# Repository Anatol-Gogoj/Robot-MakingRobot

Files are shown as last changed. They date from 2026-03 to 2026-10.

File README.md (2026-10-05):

# Robot-Making Robot (RMR)

Associated with https://arxiv.org/abs/2608.00369

A custom 3-axis gantry robot driven by Marlin firmware on an Arduino Mega 2560. This is **not** a 3D printer — it's a pick-and-place / dispensing system with three auxiliary linear actuators, two servos, and a solenoid valve. Marlin is repurposed here purely as a motion controller because it provides production-grade G-code parsing, trapezoidal motion planning, and multi-axis stepper coordination out of the box.

## Repository Structure

```
Robot-MakingRobot/
├── Marlin-2.1.2.7/              # Full Marlin 2.1.2.7 source tree
│   └── Marlin/
│       ├── Configuration.h          # Main firmware config (heavily customized)
│       ├── Configuration_adv.h      # Advanced config + SPINCOATER feature flag
│       └── src/
│           ├── pins/ramps/
│           │   └── pins_RAMPS_14_RMR.h  # Custom pin mapping (J endstop on pin 23, Serial2 freed)
│           ├── core/boards.h            # Board ID registration (patched)
│           ├── pins/pins.h              # Board routing (patched)
│           ├── feature/
│           │   ├── spincoater.h         # ODrive S1 communication namespace
│           │   └── spincoater.cpp       # ODrive Serial2 raw ASCII protocol layer
│           ├── gcode/calibrate/G28.cpp  # Custom homing order (patched)
│           ├── gcode/control/
│           │   ├── M42.cpp              # DIRECT_PIN_CONTROL (patched: S<=1 guard)
│           │   ├── M280.cpp             # Servo handling (patched)
│           │   ├── M750.cpp             # Spincoater spin cycle
│           │   ├── M751_M752.cpp        # Spincoater home datum / index search
│           │   ├── M753.cpp             # ODrive UART diagnostic
│           │   └── M754.cpp             # ODrive encoder configuration dump (read-only)
│           ├── MarlinCore.cpp           # Patched: spincoater disarm in kill() and in setup()
│           └── inc/SanityCheck.h        # Servo deactivation check bypass (patched)
├── SpincoaterStage/              # Benchtop test firmware (Nano RP2040 — reference only)
│   ├── src/main.cpp                 # Standalone spincoater firmware v2.6
│   ├── SpincoaterDashboard.html     # Standalone spincoater Web Serial dashboard
│   └── INTEGRATION_PLAN.md         # Integration design rationale (STALE — see note below)
├── RMR_Controller.html           # Unified Web Serial controller (click-optimised, debug/tuning)
├── RMR_Touch.html                # Touchscreen-optimised Web Serial UI (operation)
├── RMR_SegmentRunner.html        # Standalone segment runner + named recipes (E-axis dispense — port before use)
├── fullcode.gcode                # Production DEA layer program (dispense step still E-axis — port before use)
├── LayerCycle.gcode              # Spin-coating layer cycle (E-axis dispense — port before use)
├── LayerCycle.segments.gcode     # LayerCycle with segment markers + parameters for the Segment Runner
├── SpinCoatUVCure.gcode          # April 2026 Copilot protocol, never run (E-axis)
├── DemoProgram.gcode             # Demo pick-and-place cycle
├── tests/                        # Stub-DOM harness for the browser pages (Node; never run here)
├── tools/contrast_check.py       # WCAG contrast checker for the UI colour themes
├── pi-panel/                     # Raspberry Pi touch-panel bridge, GPIO config, systemd unit, README
├── PIN_MAP.md                    # Consolidated pin map + wiring reference (authoritative bench doc)
├── SpincoaterPinMap.jfif         # ODrive S1 J11 connector pinout image
├── ODRIVE_CONFIG.md              # ODrive S1 configuration as recorded 2026-08-13
├── RUN_SHEET.md                  # Bench run sheet (four lanes, Tasks 1–15) with dated results
├── HANDOFF-2026-09-14.md         # Frozen: the 2026-09-14 consolidation handoff
├── HANDOFF-2026-08-19.md         # Superseded: August bench results
├── HANDOFF-2026-08-14.md         # Superseded: the modulo-one-turn index finding
├── HANDOFF.md                    # Original 2026-08-11 handoff: reasoning behind the spincoater stack
├── AI_ATTRIBUTION.md             # AI assistance disclosure
├── CAD/                          # FreeCAD sources + STEP exports for printed parts
├── claude.md                     # Detailed firmware architecture & project docs
└── README.md                     # This file
```

`RMR_Controller.html` and `RMR_Touch.html` **are** the machine's UI — the Controller for
debugging and tuning, the Touch UI for operation. Do not start a third one.

`SpincoaterStage/INTEGRATION_PLAN.md` is a historical design record, not a plan. Its M750
parameter table is wrong: it documents `A`/`C` as accelerations in rev/s², but the firmware
parses them as ramp *times* in seconds. Treat `claude.md` as authoritative.

## Current State

The spincoater firmware stack that was open all summer (#38, #39, #51, #56, #57, #58, plus #70 M754
and #76) was merged into `main` on 2026-09-14 as one consolidation, PR #106; the September UI work
(sequencer homing gate, argon purge, colour themes, Touch UI syringe C-axis port) followed as PR #107.
The merged firmware compiles (`pio run -e mega2560`); the last hardware evidence recorded in this repo is
from the 2026-08-17/19 bench sessions. The Spin Coater Subsystem section below describes `main`.

`HANDOFF-2026-09-14.md` records the consolidation: what merged, the conflict resolutions that were
decisions, and the four UI pull requests that were deliberately left out. It and the older `HANDOFF*.md`
files are frozen history; session state is not kept in the repo. `RUN_SHEET.md` is the bench checklist;
`HANDOFF-2026-08-19.md` holds the August results.

## Hardware Overview

### Motion System

The gantry has three Cartesian axes (X, Y, Z) plus three auxiliary linear actuators. The Filter Feed and Syringe Height are mapped as Marlin I/J linear axes (with full homing and endstop support), while the Syringe is the sole extruder (E0). All stepper drivers are external DM556T units (optoisolated PUL/DIR/ENA inputs) driven directly from Mega GPIO pins — there is no RAMPS shield, though the pin mapping inherits from RAMPS 1.4 for the gantry axes.

| Marlin Axis | G-Code | Function | Drive | Steps/mm |
|---|---|---|---|---|
| X | X | Gantry X | GT2-14 belt | 57.14 |
| Y + Y2 | Y | Gantry Y | GT2-14 belt (2 motors, 2 drivers, firmware-synchronized via `Y2_DRIVER_TYPE`) | 57.14 |
| Z | Z | Gantry Z | 5 mm lead screw | 320 |
| I | A | Filter Feed | 5 mm lead screw | 320 |
| E0 | E | Syringe | 1 mm lead screw | 1600 |
| J | B | Syringe Height | 5 mm lead screw | 320 |

Steps/mm formula: `(motor_steps_per_rev × microstepping) ÷ linear_travel_per_rev`. All drivers are set to 1/8 microstepping (1600 steps/rev with 200-step motors).

### Tuned Motion Parameters

| Parameter | X | Y | Z | A (Filter) | B (Syr.Ht) | E (Syringe) |
|---|---|---|---|---|---|---|
| Max feedrate (mm/s) | 400 | 333 | 50 | 33 | 50 | 8 |
| Max feedrate (mm/min) | 24000 | 20000 | 3000 | 2000 | 3000 | 500 |
| Max acceleration (mm/s²) | 500 | 200 | 100 | 150 | 50 | 500 |
| Travel limit (mm) | 770 | 200 | 186 | 343 | 295 | 125 |

> Y travel reaches 200 mm only on the right half (X ≥ 350); on the left half keep Y ≤ 150 mm to clear fixtures.

### End Effectors and Peripherals

- **Gripper servo** — GPIO 5, `M280 P0 S<angle>`, range 90° (closed) to 170° (open)
- **Lid servo** — GPIO 6, `M280 P1 S<angle>`, 0–180° range
- **UV lamp relay** — GPIO 4, `M42 P4 S1` = ON / `M42 P4 S0` = OFF (current active-HIGH modules)
- **Solenoid valve relay** — GPIO 42, `M42 P42 S1` = ON / `M42 P42 S0` = OFF (current active-HIGH modules)

Both relays are opto-isolated modules powered from a dedicated 3.3 V buck converter rail (shared ground with the Mega). The current modules are active-HIGH (S1 = energize). The original Bestep JQC3F-03VDC-C modules were active-LOW (S0 = energize). The HTML UI uses explicit ON/OFF button pairs with hardcoded S values, so correct polarity is handled by which button the user presses.

Servos deactivate 2 seconds after positioning (`DEACTIVATE_SERVOS_AFTER_MOVE`) to prevent PWM jitter.

### Limit Switches

All five homing axes have endstops:
- X endstop on pin 3 (X_MIN, interrupt-capable)
- Y endstop on pin 14 (Y_MIN)
- Z endstop on pin 40 (Z_MIN — moved from pin 18/TX1 due to EMI)
- I (Filter Feed) endstop on pin 15 (I_MAX — homes to far end)
- J (Syringe Height) endstop on pin 23 (J_MIN — moved from pin 17/TX2 to free Serial2 for ODrive)
- Syringe (E0) has no endstop

All switches are normally-open, wired common→GND / NO→signal, with internal pullups enabled. `G28` (home all) is safe to send.

## Firmware Details

### Custom Board Definition

A custom board `BOARD_RAMPS_14_RMR` (ID **1025**) inherits from stock RAMPS 1.4 and overrides pin assignments for the I/J linear axes and E0 extruder. **ID 1020 is stock `BOARD_RAMPS_14_EFB` — using it silently selects the wrong pin file.** The following Marlin source files are modified:

| File | Change |
|---|---|
| `Marlin/src/pins/ramps/pins_RAMPS_14_RMR.h` | Custom pin map, conflict resolution, J endstop on pin 23 |
| `Marlin/src/core/boards.h` | Board ID `1025` registration (`boards.h:50`) |
| `Marlin/src/pins/pins.h` | Routing `MB(RAMPS_14_RMR)` → pins file |
| `Marlin/src/gcode/calibrate/G28.cpp` | Custom homing order Z→Y→J→X→I, gripper close before X |
| `Marlin/src/gcode/control/M42.cpp` | Added `pin_status <= 1` early return so digital-only writes skip `hal.set_pwm_duty()` on AVR (prevents Timer0/Timer1 conflicts) |
| `Marlin/src/gcode/control/M280.cpp` | Servo clamp removed (soft limits in HTML only). POLARGRAPH gate on T parameter removed — `M280 Px S<angle> T<ms>` now works on all servos for timed linear interpolation. |
| `Marlin/src/gcode/control/M750.cpp` | Spincoater spin cycle handler |
| `Marlin/src/gcode/control/M751_M752.cpp` | Spincoater home datum / index search |
| `Marlin/src/gcode/control/M753.cpp` | ODrive UART diagnostic |
| `Marlin/src/feature/spincoater.h/.cpp` | ODrive S1 Serial2 raw ASCII communication layer |
| `Marlin/src/MarlinCore.cpp` | Spincoater disarm in `kill()` and in `setup()` (startup safety disarm) |
| `Marlin/src/inc/SanityCheck.h` | DEACTIVATE_SERVOS_AFTER_MOVE check bypassed |
| `Marlin/Configuration_adv.h` | SPINCOATER feature flag + defaults; `DIRECT_PIN_CONTROL` for M42 relays; `EMERGENCY_PARSER` enabled so M112 bypasses the queue during a blocking M750 |
| `ini/features.ini` | Build system registration for spincoater source files |

Several stock RAMPS pins are reassigned to free GPIOs for the auxiliary motors (e.g., pin 2 repurposed from X_MAX to I_STEP, pin 9 from FAN to I_DIR). Pins 16/17 are occupied by Serial2 (ODrive link). Pins 19/20/21 conflict with Serial1 and I2C — those peripherals cannot be used without rewiring.

### Key Configuration Choices

- `EXTRUDERS 0` — no extruder; the syringe is the homeable K axis (G-code `C`), Filter Feed and Syringe Height are the I/J linear axes (`A`/`B`), all with endstops and homing
- `AXIS4_NAME 'A'`, `AXIS5_NAME 'B'`, `AXIS6_NAME 'C'` — G-code letters for the I/J/K axes
- All temperature sensors disabled (`TEMP_SENSOR_* 0`) — no heaters on this machine
- `EXTRUDE_MINTEMP 0` — moot since `EXTRUDERS 0`: there is no E axis and no cold-extrusion check
- `INVERT_Z_DIR`, `INVERT_I_DIR`, `INVERT_J_DIR`, `INVERT_K_DIR` all `true` — Z/I/J verified by physical testing; K (syringe) is flipped so `-C` homes toward the open end — verify on first use
- Custom homing order: lid open (30°) → Z → Y → J(Syr.Ht) → gripper close (90°) → X → I(Filter Feed)
- `DEACTIVATE_SERVOS_AFTER_MOVE` with 2-second hold — prevents servo jitter

## Spin Coater Subsystem

The spin coater uses an ODrive S1 motor controller driving a D5312s-330kV brushless motor with an AMT102 incremental encoder. The ODrive is controlled directly from the Mega 2560 over Serial2 (pins 16/17) at 115200 baud using the ODrive raw ASCII protocol — there is no second Arduino.

```
Mega 2560 (Marlin + M750/M751/M752/M753/M754)  ──Serial2 (115200)──►  ODrive S1  ──►  Motor
```

### Spincoater G-Codes

```gcode
M750 S5000 D30 A5 C1 H1   ; spin cycle: 5000 RPM, 30s dwell, 5s ramp-up, 1s ramp-down, home after
M751                       ; set current position as the 0° home datum
M752                       ; encoder index search, then move back to the saved datum
M753                       ; UART diagnostic — probes ODrive link, reports raw response
M754                       ; encoder configuration dump (read-only) — answers the index-reference question over UART
```

**M750** — blocking spin cycle. `S` = RPM, `D` = dwell seconds, `A` = ramp-up **time in
seconds**, `C` = ramp-down **time in seconds**, `H` = home after (0/1). Defaults are
S5000 D30 A5 C1 H1. All four numeric values must be > 0 or the command aborts with
`ERR: All values must be > 0`. `A`/`C` are converted internally to ODrive ramp rates
(`accel = (rpm/60)/A` rev/s²) — they are *not* accelerations.

Phase order is: boot (first call only) → CONNECTING → Vbus read → CALIBRATING/CLOSED_LOOP →
RAMP_UP → MEASURING → RAMP_DOWN → SETTLING → STOPPED → optional index home. It emits
real-time telemetry and Welford's online statistics (mean, std dev, min, max RPM) over serial.
The cycle can abort at several points; every abort still returns a bare `ok` to the host
(see gotcha 13). Judge success only by the terminal line:
`OK: CYCLE_COMPLETE` vs `ERR: CYCLE_COMPLETE_NO_HOME`.

**M751** — sets the current encoder position as the 0° datum. It can now fail: it refuses
without two consistent position reads, and refuses if the axis is turning faster than about
3 RPM. Success prints `OK: HOME_SET`; a failure *after the ODrive boots* prints a reason plus
`ERR: HOME_SET_FAILED`. If the deferred `boot()` itself fails, M751 prints only
`ERR: ODrive boot failed` and emits **no terminal marker at all**.

**M752** — runs the ODrive encoder index search, verifies `axis0.procedure_result`, then
re-arms closed loop and commands a slow trapezoidal move **back to the saved datum**
(vel_limit 0.25 turns/s ≈ 15 RPM, 8 s watchdog). **The chuck physically rotates.** It never
moves an existing datum; it only establishes one if none exists. Success prints
`OK: INDEX_COMPLETE`; any failure *after the ODrive boots* prints `ERR: INDEX_HOME_FAILED` (and,
if it was the settle that timed out, `ERR: INDEX_INCOMPLETE -- datum not reached` immediately
before it). If the deferred `boot()` itself fails — a dead link, the most likely bench failure and
the leading suspect in issue #46 — M752 prints only `ERR: ODrive boot failed` and emits **no
terminal marker at all**.

A common M752 refusal is `ERR: Position <n> is >1 turn from home datum <n> -- refusing settle`.
It means the reported position and the datum are in different encoder frames, so the move
would crawl for thousands of turns. The only way out is `M751`. Whether an ODrive 0.6.x index
search actually re-references `pos_estimate` is **unverified on this machine** and is the
open bench question behind this behaviour.

**M753** — UART diagnostic only. It calls `Spincoater::init()`, sends `r vbus_voltage`, and
dumps raw bytes as `DIAG:` lines for up to 2 s. It does not boot the ODrive, does not touch
the datum, and does not move anything — so it is the correct first command on a cold bench.

The ODrive *probe/boot* sequence is deferred to the first M750/M751/M752. Serial2 itself is
opened during Marlin `setup()`, which transmits two ODrive IDLE requests on **every** board
reset (startup safety disarm), so pin 16 is not idle at power-on.

The `SpincoaterStage/` directory contains the original standalone firmware (Nano RP2040 Connect) and dashboard used for benchtop testing. These are reference files only — the production system uses the integrated Marlin M-codes, and none of the Nano's `SPIN`/`STOP`/`HOME` text commands exist in Marlin.

## Building and Uploading

### Prerequisites

- [VS Code](https://code.visualstudio.com/) with the [PlatformIO](https://platformio.org/) extension
- USB cable to the Arduino Mega 2560

### Build Steps

1. Open the `Marlin-2.1.2.7/` directory in VS Code with PlatformIO.
2. Ensure `platformio.ini` has `default_envs = mega2560`.
3. Build: click the PlatformIO checkmark button, or run:
   ```
   pio run -e mega2560
   ```
4. Upload: click the PlatformIO arrow button, or run:
   ```
   pio run -e mega2560 -t upload
   ```

### Serial Connection

Connect via the included `RMR_Controller.html` or `RMR_Touch.html` web UI (Chrome/Edge, Web Serial API), Pronterface, or any serial terminal at **250000 baud**. Port is typically `/dev/ttyACM0` on Linux or `COM3` on Windows.

## Using the Machine

### Startup Sequence

```gcode
G28              ; home all axes (lid open → Z → Y → J → gripper close → X → I → K/Syringe) — safe, all have endstops
G28 X Y Z A B    ; home the gantry + aux axes WITHOUT retracting the syringe
```

A bare `G28` also homes the syringe (Marlin K axis, G-code letter `C`) and leaves the plunger fully open at `C0`, so no `G92` reset is needed — the syringe is a homed absolute axis.

### Moving the Gantry

```gcode
G1 X100 Y50 F3000    ; move to (100, 50) at 50 mm/s
G1 Z10 F600          ; lower Z 10 mm at 10 mm/s
```

Feedrates are in mm/min. Max recommended: X 24000, Y 20000, Z 3000.

### Driving Auxiliary Motors

Each auxiliary motor has its own G-code axis letter — no tool switching needed:

```gcode
G1 A50 F1000     ; move Filter Feed to 50 mm at 1000 mm/min
G1 B20 F600      ; move Syringe Height to 20 mm
G1 C5 F300       ; push the syringe plunger to 5 mm from home (+C = dispense; C0 = fully open)

G91              ; relative mode
G1 C5 F300       ; dispense a further 5 mm from the current plunger position
G90              ; back to absolute mode
```

The syringe is a homed absolute axis (Marlin K axis, G-code letter `C`; `C0` = plunger fully open, soft-endstop limit 125 mm). Do **not** use `G92 C0` to re-zero it — that defeats the soft endstops. For a relative "dispense N mm" nudge, wrap the move in `G91` / `G90` as shown. The old extruder idioms `G1 E…` / `G92 E0` are silently ignored by the current firmware (there is no E axis).

### Servos, UV Lamp, and Solenoid

```gcode
M280 P0 S90      ; close gripper (90°)
M280 P0 S170     ; open gripper (170°)
M280 P1 S0       ; set lid servo to 0°
M280 P1 S30 T800 ; open lid over 800ms (timed linear interpolation)

; Relays (current modules are ACTIVE-HIGH):
M42 P4  S1       ; UV lamp ON        (active-high)
M42 P4  S0       ; UV lamp OFF
M42 P42 S1       ; solenoid valve OPEN  (active-high)
M42 P42 S0       ; solenoid valve CLOSED
```

The current relay modules are active-HIGH (S1 = energize, S0 = de-energize). The original Bestep JQC3F-03VDC-C modules were active-LOW (S0 = ON, S1 = OFF). Always comment the intent in production G-code (e.g. `M42 P4 S1 ; UV_ON`) because the S-value meaning depends on which relay module is installed.

### Spin Coating

```gcode
M753                       ; UART diagnostic — safe first command, does not boot or move
M752                       ; index search + return to datum — THE CHUCK ROTATES
M751                       ; set current position as 0° datum (refuses if the rotor is moving)
M750 S3000 D10 A5 C1 H1    ; 3000 RPM, 10s dwell, 5s ramp-up, 1s ramp-down, home after
```

`A` and `C` are ramp **times in seconds**, not accelerations. `A5 C1` means a 5-second
ramp-up and a 1-second ramp-down.

M750 is blocking — Marlin will not process further commands until the cycle completes,
except `M112`/`M108`/`M410`, which `EMERGENCY_PARSER` dispatches straight from the serial
RX path. Use within G-code programs to sequence spin coating after gantry positioning
(see `fullcode.gcode`).

Watch the serial log, not the phase indicator. Success and failure are distinguished only by
the terminal line:

| Command | Success | Failure |
|---|---|---|
| M750 | `OK: CYCLE_COMPLETE` | `ERR: CYCLE_COMPLETE_NO_HOME` (H1 home failed), or no terminal line at all on an earlier abort |
| M751 | `OK: HOME_SET` | `ERR: HOME_SET_FAILED` |
| M752 | `OK: INDEX_COMPLETE` | `ERR: INDEX_HOME_FAILED` |

`WARN:` lines carry every datum-integrity message (datum preserved, datum established,
"run M751"). Neither UI highlights them — read them in the console.

### Runtime Tuning (no rebuild needed)

```gcode
M201 X500 Y200 Z100 A150 B50 C500   ; set max acceleration (mm/s²) — C = Syringe
M203 X400 Y333 Z50 A33 B50 C8       ; set max feedrate (mm/s) — C = Syringe
M500             ; NOT AVAILABLE — EEPROM_SETTINGS is disabled (Configuration.h:2217).
                 ;   Reports "EEPROM disabled" and saves nothing.
M501             ; DESTRUCTIVE — does NOT load from EEPROM. It resets every setting to the
                 ;   compiled-in Configuration.h defaults, discarding all runtime tuning.
M503             ; report all active settings (works)
```

### Diagnostics

```gcode
M119             ; report endstop states
M114             ; report current position
M999             ; recover from "stopped" errors (NOT from M112 — after M112, reset/reconnect the board)
```

## Web Controller

There are two UIs, both standalone browser pages driving the machine over Web Serial
(Chrome/Edge required): `RMR_Controller.html` (click-optimised, full control — use for
debugging and tuning) and `RMR_Touch.html` (touchscreen-optimised, tabbed layout — use for
operation). They share the same serial contract and the same spincoater panel logic.

`RMR_Controller.html` features:

- XY/Z jog pads with configurable step sizes and per-axis feed sliders
- Per-axis auxiliary motor controls with individual feed sliders (A, B, C)
- Collapsible acceleration tuning panel (M201) with per-axis sliders and EEPROM save
- Gripper servo slider (90°–170°) with Open/Close buttons and full-range override textbox
- Spincoater panel — RPM/Duration/Rise/Sink inputs, live RPM gauge, SVG circular position dial, Welford stats cards, phase indicator, and four buttons:
  - **Start Spin** (M750), **Set Home** (M751), **Index Home** (M752 — rotates the chuck)
  - **Stop** — sends **M112**. This is not a soft stop: it kills the firmware, freewheels the chuck, needs a board reset to recover, and loses the datum. The Process Sequencer's Stop is the soft one: it sends `M410`, which a running `M750` polls and honours by zeroing the rotor (`STATE:STOPPED` + `OK: ABORTED`, untested on hardware).
- E-Stop (M112) — recover via board reset (disconnect/reconnect USB); the M999 Reset button only clears the softer "stopped" state
- Position readout with auto-report polling
- G-code program runner with Load .gcode, Run/Pause/Stop, and wait-for-ok sequencing
- Raw G-code input with command history
- Keyboard shortcuts: Arrow keys = XY, PgUp/PgDn = Z, Esc = E-Stop
- **Process Sequencer** tab — Homing / Syringe / Spin Coater / UV / Stamp recipe blocks with per-block Run, Run All and Repeat. The Syringe block doses with a post-dose dwell (2 s default) before a pullback at its own feed (sized on the bench to stop the drip; the max-retract cap defaults to 2 mm), dose / retract / barrel-stroke guards, a purge routine and an idle warning — the numbers for the 150 mL catheter-tip syringe are in `DISPENSE_150ML.md`
- **Run Log** tab — a per-device manufacturing log for multilayer DEAs that mirrors the MLDEA reference sheet: one row per dielectric layer (dispense time, volume, RPM set / settled, UV on, cure set / actual, nominal height) and one per electrode (P/N, filter pressed, hold, feeder side), filled in automatically by the sequencer, editable cell by cell (the recorded value is kept underneath), with **Hold** / **Break** buttons that pause a run between commands at the end of the layer (or after the next cure / current block) and record the pause as a row, a **Log on/off** switch, manual "mark now" buttons (all filter pressing is by hand today), a journal of every event including re-runs, and Excel / CSV / JSON export — the `.xlsx` reproduces the reference sheet's layout and formulas. Saved in the browser; optionally auto-saved to a folder you pick. Design notes: `RUN_LOG_PLAN.md`
  - **Homing gate:** Syringe, UV and Stamp stay locked until a full home (bare `G28`) has completed; Spin Coater and Homing are always available. Re-locks after E-stop, reset, motors-off, a firmware restart or a motor-power loss.
  - **Argon purge:** the UV block can open the argon solenoid a configurable number of seconds before UV-on and close it a configurable number of seconds after UV-off (negative values allowed); the lamp and solenoid always end off/closed, even on Stop.
  - UV progress is drawn on a canvas showing the argon / UV / argon segments — click it to cycle bar → wave → snake.
- **Colour themes** (header selector; Touch UI: Advanced tab): Auto, Midnight, Tol dark, Tol light, Tol high-contrast — Paul Tol colour-blind-safe palettes, every text/surface pair WCAG AA checked by `tools/contrast_check.py`; keyboard focus rings and reduced-motion support.

`RMR_Touch.html` is the touch-panel variant of the same UI (large controls, tabbed layout) with the same sequencer, themes and Pi-bridge transport.

## Important Gotchas

1. **Axis naming:** G-code uses `A` and `B` for the Filter Feed and Syringe Height axes (not `I`/`J`). This applies to all commands: `G1`, `M201`, `M203`, `G28`, etc.
2. **The syringe is the C axis, not an extruder:** `EXTRUDERS 0`; the plunger is Marlin's K axis with G-code letter `C` (`+C` = dispense, `C0` = fully open, homed, soft-endstop 0–125 mm). `G92 E0` / `G1 E…` are silently ignored — no error — so any program still using them dispenses nothing. `fullcode.gcode`, `LayerCycle*.gcode`, `SpinCoatUVCure.gcode` and `RMR_SegmentRunner.html` still do (see `HANDOFF-2026-09-14.md` §5).
3. **Filter Feed homes to MAX:** Unlike all other axes which home to MIN, the Filter Feed (A axis) homes to its far-end endstop (I_MAX, pin 15).
4. **Servo deactivation:** Servos go limp 2 seconds after positioning. If the gripper needs to actively hold force, `DEACTIVATE_SERVOS_AFTER_MOVE` must be disabled (requires rebuild) or an external servo controller used.
5. **E-Stop recovery:** `M112` fully kills the firmware and **cannot** be recovered with `M999` — reset the board (disconnect/reconnect USB or power-cycle). On reboot the firmware automatically disarms the spincoater. `M999` only recovers from the softer "stopped" state. `EMERGENCY_PARSER` is enabled, so `M112`/`M108`/`M410` act immediately from the serial RX path instead of queueing behind a blocking M750. Side effect: `M0`/`M1` are now compiled in and will **pause until an `M108` arrives** — previously they returned "Unknown command". Any production G-code containing `M0`/`M1` will stall. **This side effect has not been bench-checked.**
6. **Pins 16/17 (Serial2)** are occupied by the ODrive S1 link. **Pins 19/20/21** conflict with Serial1 and I2C. Adding an I2C LCD or additional serial device requires rewiring motors.
7. **Direction inversions:** Z, I, and J axes all have `INVERT_*_DIR true`. If a new axis is added or a motor is rewired, verify direction during first test.
8. **AVR `println()` and ODrive:** On AVR, `Serial.println()` sends `\r\n`. The ODrive ASCII protocol expects bare `\n` — the stray `\r` causes "unknown command" errors. All ODrive UART writes use `print()` + `write('\n')` instead.
9. **M42 hijacks hardware timers on AVR:** Stock Marlin's `M42.cpp` always falls through to `hal.set_pwm_duty(pin, pin_status)` on AVR, which maps to `analogWrite()` and grabs the pin's hardware timer compare unit — even for `S0` and `S1`. On pins tied to Timer1 (e.g. pin 11 = OC1A, used by Marlin's stepper ISR) this causes intermittent pin-fighting where `M42` appears to work once and then stops. Our patched `M42.cpp` adds a `pin_status <= 1` early return so digital-only writes always take the pure `digitalWrite` path. For relay pins, prefer pure-GPIO pads with no timer compare unit (pin 42 = PL7 is used for the solenoid valve; pin 4 = OC0B is tolerable only because of the patch).
10. **Relay module polarity:** The current relay modules are active-HIGH (`M42 Pxx S1` = energize, `M42 Pxx S0` = de-energize). The original Bestep JQC3F-03VDC-C modules were active-LOW (reversed polarity). The HTML UI uses explicit ON/OFF button pairs with hardcoded S values, so the correct polarity is handled by button choice regardless of module type.
11. **`Servo::move()` vs `Servo::write()` in interpolation loops:** `move()` calls `attach + safe_delay(SERVO_DELAY) + detach` per invocation — with SERVO_DELAY=2000, that is 2s per step. For tight ramp loops, use `write()` with manual `attach(0)` before and `write(final)+safe_delay(250)+detach` after. The M280 T parameter uses this approach. Default lid ramp time in the HTML UIs is 800ms.
12. **M752 and `M750 ... H1` physically rotate the chuck.** After the index search the firmware re-arms closed loop and commands a slow trapezoidal move back to the saved datum — up to ~15 RPM for up to 8 seconds. Do not run either with the lid open or with anything resting on the chuck.
13. **`ok` does not mean a spincoater command succeeded.** Every M750/M751/M752 failure path returns normally, so Marlin still emits `ok`. The Program Runner's wait-for-ok will happily continue to the next layer after a failed home. Judge success only by the terminal marker (`OK: CYCLE_COMPLETE` / `OK: INDEX_COMPLETE` / `OK: HOME_SET`).
14. **Spincoater failure tokens used to render as successes.** Until 2026-09-14 both UIs matched tokens by substring, so `ERR: CYCLE_COMPLETE_NO_HOME` showed a green "Cycle complete" and `ERR: HOME_SET_FAILED` showed "Home datum set". `main` now dispatches `ERR:` / `OK:` by message class (PR #84's commit, merged with #106): any `ERR:` sets the error phase, and the Touch UI toasts it. Still unhandled: `WARN:` lines, and the `STATE:STOPPED` / `OK: ABORTED` pair a Process Sequencer Stop produces — read the console.
15. **The spincoater datum is RAM-only.** `_homePos` is not stored in EEPROM, so it is lost on every board reset — including the DTR reset the browser triggers when it connects, and the reset that is the only recovery from `M112`. After any reconnect or E-stop, re-run `M751` before any layer that depends on angular registration.
16. **`M112` disarms the spincoater, it does not brake it.** `kill()` requests ODrive IDLE, so the rotor **freewheels** to a stop. This is deliberate — there is no confirmed brake resistor and regen from a high-RPM chuck could overvolt the DC bus. Coast-down time from full speed has never been measured on this machine.
17. **Sequencer homing gate:** the web UIs track "all axes homed" in the browser. A manual bare `G28` is followed by `M118 RMR:HOMED_ALL`, which Marlin prints back only after the homing finishes — that line unlocks the Syringe / UV / Stamp blocks on every client of the Pi bridge. Partial homing (`G28 X Z`) does not unlock; E-stop, `M999`, `M18`, a firmware restart or `MOTOR POWER LOST` re-lock.

## AI Attribution

Portions of this project's documentation, firmware configuration, and supporting code were generated or edited with the assistance of Claude (Anthropic). All AI-generated content was reviewed and validated by the project author. See [AI_ATTRIBUTION.md](AI_ATTRIBUTION.md) for details.

## License

The Marlin firmware is licensed under the GPL v3. See the `Marlin-2.1.2.7/` directory for full license text. Project-specific files (pin map, controller UI, configurations) are provided as-is for this specific machine build.

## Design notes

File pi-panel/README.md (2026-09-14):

# RMR Integrated Touch Panel (Raspberry Pi)

Turns a Raspberry Pi + a generic 10″ touchscreen into a built-in operator panel
for the machine. The Pi owns the USB link to the Arduino Mega (Marlin); the
existing web UI (`RMR_Controller.html`) runs in a browser on the Pi and talks to
the Pi over a **WebSocket** instead of the browser's Web Serial API.

Because the browser no longer needs Web Serial, **any browser works** — Firefox
or a lightweight WebKit kiosk (`cog`) — no Chromium requirement.

## Architecture

```
   10" touch  (HDMI video  +  USB touch-HID)
        │
   ┌────┴─────┐   browser (Firefox / cog kiosk) → RMR_Controller.html?transport=ws
   │  Pi 4/5  │        │  WebSocket ws://localhost:8765   (+ static HTTP :8000)
   │          │   ┌────┴─────────────┐
   │          │   │ rmr_bridge.py    │  owns the serial port, fans out to all clients
   │          │   └────┬─────────────┘
   └────┬─────┘        │
        │ USB  /dev/rmr-mega @ 250000     ← the only control link
   ┌────┴─────┐
   │ Mega 2560│   Marlin  (M750 drives the spincoater)
   └────┬─────┘
        │ Serial2 UART (pins 16/17, 115200)
   ┌────┴─────┐
   │ ODrive S1│──▶ motor
   └────┬─────┘
        ╎ USB → Pi  (OPTIONAL: /dev/rmr-odrive, for odrivetool / debugging only)
```

The ODrive is driven **by the Mega** over Serial2 (`M750/M751/M752`), so run-time
control is one USB link (Pi → Mega). Wiring the ODrive's USB to the Pi is only a
convenience for `odrivetool` during calibration/tuning — it is not used at run time.

## Hardware

- **Raspberry Pi 4 (2–4 GB) or Pi 5** — a Pi 3 struggles with a browser UI.
- **10″ touchscreen:** HDMI video + **USB-HID capacitive touch** is the most
  universal (plug-and-play on Linux, no driver). Avoid panels that need a vendor
  touch driver.
- Its own solid **5 V / 3 A** supply for the Pi (don't power it from the Mega).
- Active cooling if it lives in an enclosure.

## One-time setup

### 1. OS + repo
Install Raspberry Pi OS (64-bit, Bookworm). Clone this repo, e.g. to
`/home/pi/Robot-MakingRobot`.

### 2. Python bridge dependencies (isolated venv)
```bash
cd /home/pi/Robot-MakingRobot/pi-panel
python3 -m venv .venv
.venv/bin/pip install -r requirements.txt
```
`gpiozero` (for physical buttons) is already present in Raspberry Pi OS.

### 3. Stable serial device names (udev)
So the Mega is always `/dev/rmr-mega` regardless of USB enumeration order:
```bash
# find your board's USB IDs first:
lsusb
udevadm info -a -n /dev/ttyACM0 | grep -E 'idVendor|idProduct'
# edit 99-rmr-serial.rules to match, then:
sudo cp 99-rmr-serial.rules /etc/udev/rules.d/
sudo udevadm control --reload-rules && sudo udevadm trigger
```
Confirm `ls -l /dev/rmr-mega` now points at the Mega.

### 4. Test the bridge manually
```bash
cd /home/pi/Robot-MakingRobot
pi-panel/.venv/bin/python pi-panel/rmr_bridge.py \
    --port /dev/rmr-mega --baud 250000 \
    --serve-dir "$PWD" --http-port 8000 --ws-port 8765
```
You should see `[serial] opened /dev/rmr-mega` and `[ws] listening …`. Open a
browser on the Pi to **`http://localhost:8000/RMR_Controller.html`** — it
auto-detects HTTP and connects to the bridge; the console shows
`Bridge connected`.

### 5. Run on boot (systemd)
```bash
# edit paths/User in rmr-bridge.service if needed, then:
sudo cp pi-panel/rmr-bridge.service /etc/systemd/system/
sudo systemctl daemon-reload
sudo systemctl enable --now rmr-bridge.service
journalctl -u rmr-bridge -f      # watch it
```

### 6. Kiosk browser autostart (no Chromium needed)
Point a full-screen browser at the UI. Two good options:

- **Firefox kiosk:** `firefox --kiosk "http://localhost:8000/RMR_Controller.html"`
- **cog** (lean WPE WebKit): `sudo apt install cog && cog "http://localhost:8000/RMR_Controller.html"`

Autostart on Bookworm (labwc/wayfire desktop) — add to `~/.config/wayfire.ini`:
```ini
[autostart]
panel = firefox --kiosk http://localhost:8000/RMR_Controller.html
blank = swayidle timeout 0 'true'    # or disable screen blanking via raspi-config
```
On the older X11 desktop, put a `.desktop` launcher in `~/.config/autostart/`.
Disable screen blanking with `raspi-config` → Display, or `xset s off -dpms` (X11).

### 7. On-screen keyboard (touch input for text fields)
The panel has text/number fields (raw G-code, preset names, tunables), so add a
virtual keyboard:
- Wayland (Bookworm): `sudo apt install wvkbd` (or `squeekboard`)
- X11: `sudo apt install onboard` (or `matchbox-keyboard`)

## Using it

- **On the Pi:** `http://localhost:8000/RMR_Controller.html` (bridge mode auto-selected).
- **Touch layout:** swap the URL to `RMR_Touch.html` for the big-target UI (same
  bridge; it has the Process Sequencer as its **Recipe** tab).
- **From a phone/laptop on the LAN:** `http://<pi-hostname>.local:8000/RMR_Controller.html`
  — multiple clients can be connected at once; every serial line and every command
  (including physical-button presses) is mirrored to all of them.

### Transport selection (URL)
The page auto-picks its transport, override with query params:
| Situation | Transport | How |
|---|---|---|
| Served over `http(s)://` (the Pi) | WebSocket bridge | automatic |
| Opened as a local `file://` (dev laptop) | Web Serial | automatic |
| Force bridge | WebSocket | `?transport=ws` |
| Force Web Serial | Web Serial | `?transport=serial` |
| Bridge on another host/port | WebSocket | `?ws=ws://host:8765` |

The header also has a **Web Serial / Pi Bridge** dropdown that overrides the
auto-pick without a URL change; the choice is remembered (`localStorage`), so a
dev laptop served over `http://localhost` can switch to Web Serial once and stay
there. The dropdown is disabled while connected, and "Web Serial" shows as
`(n/a)` in insecure contexts (plain `http://` to a LAN IP), where the browser
does not expose the API — use `localhost`, `https://`, or a local `file://`.

## GPIO I/O: buttons, status tower, E-stop sense

All optional and off unless configured. Copy `rmr_io.example.json` to `rmr_io.json`,
edit, and it's passed with `--io …/rmr_io.json` (the systemd unit already does).
Pins are BCM GPIO numbers.

**Physical buttons (gloves / dirty hands)** — momentary buttons mapped to G-code.
Default wiring is button → GPIO pin and GND (internal pull-up, active-low). Each
press calls the same path as the UI and is echoed to every connected screen. A
`cmd` may hold several lines (`\n` inside the JSON string): the example `home_all`
button sends `G28` and then `M118 RMR:HOMED_ALL` — Marlin prints that marker back
only after the homing has finished, and every browser UI uses it to unlock the
Process Sequencer's homing gate (Syringe / UV / Stamp stay locked until a full home).

**Status tower + buzzer** — a red/amber/green tower light and buzzer driven from
machine state the bridge infers off the serial stream + connection:

| State | Tower | Meaning |
|---|---|---|
| `green` | steady | connected and idle/ready |
| `amber` | steady | active — a command was sent in the last ~1.5 s |
| `red` + buzzer | pulsing | Marlin error/kill, or E-stop asserted |
| `red` | steady | serial link down (Mega unplugged / not responding) |

Omit any channel you don't have; use `"active_high": false` for active-LOW relay
or driver boards. Tower lights are usually 12/24 V — switch them from the Pi's
3.3 V GPIO through a transistor/MOSFET or relay, don't drive them directly.

**E-stop sense** — wire the auxiliary contact of your hardware E-stop to a GPIO
input so software knows it was hit: the tower goes red + buzzer, the UI is told
(`{"_rmr":"estop"}`), and if `"cmd"` is set it also sends it (e.g. `M112`). Match
`"pull"` to your contact wiring.

```json
{
  "buttons": [ { "pin": 17, "name": "estop", "cmd": "M112", "pull": "up" } ],
  "tower":   { "red": 5, "amber": 6, "green": 13, "buzzer": 26, "active_high": true },
  "estop":   { "pin": 20, "pull": "up", "cmd": "M112" }
}
```

> ⚠️ **SAFETY — the GPIO E-stop (button *or* sense) is a software convenience,
> not a safety interlock.** It sends/echoes `M112` and only works if the Pi, USB
> link, and firmware are all alive. For real safety, ALSO fit a hardware E-stop
> that physically cuts stepper-driver / ODrive motor power, independent of the Pi.
> Wire that hardware E-stop's aux contact to the `estop` sense input so the panel
> annunciates it.

## How it works (protocol)

- **Data plane** (line-oriented, 1:1 with serial): browser → bridge sends a raw
  command string (bridge appends `\n`); bridge → browser sends one raw serial
  line per message, which the UI feeds to its existing `processLine()`.
- **Meta plane** (JSON, begins with `{` and carries `_rmr`): `status` (serial
  open/closed), `tx` (every write, echoed to all clients with its source), `button`
  (a physical button fired), `estop` (sense input changed), `error`.
- The bridge holds the port open persistently, so the Mega DTR-resets **once** at
  bridge start rather than on every UI connect. It auto-reconnects the serial port
  (with backoff) if the USB drops, and the UI auto-reconnects the WebSocket.

## Troubleshooting

- **UI says "serial closed":** check `/dev/rmr-mega` exists (udev), the Mega is
  powered, and no other program holds the port. `journalctl -u rmr-bridge -f`.
- **Can't reach from another device:** the bridge binds `0.0.0.0`; check the Pi's
  firewall and that you used the Pi's hostname/IP, ports 8000 + 8765.
- **Buttons / tower / E-stop do nothing:** `gpiozero` present and `--io` pointing
  at your `rmr_io.json`? Correct BCM pin numbers and `active_high` polarity? Watch
  the bridge log at startup for `[gpio] status tower …`, `[gpio] E-stop sense …`,
  and per-button `[gpio] … -> …` lines.
- **Spincoater tuning:** connect `odrivetool` to `/dev/rmr-odrive` (USB) — the
  Mega's Serial2 link is separate and can stay connected.

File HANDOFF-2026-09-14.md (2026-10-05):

# HANDOFF — 2026-09-14

> **Frozen 2026-10-05.** This is the last in-repo handoff. Its state and next steps are as of
> 2026-09-14 and are not maintained; session state is no longer kept in the repo.

**Supersedes** `HANDOFF-2026-08-19.md` (PR #79). Its §6 "do this next" list is done or dispositioned in
§2 and §5 below. Its §3 (the Mega's intermittent USB link) and §4 (the bench laptop's GUI failures) were
not touched by anything in this handoff and are carried forward unchanged.

Claims are marked by how they were established: **[bench]** observed on the hardware, **[source]** read
out of this repo, **[build]** compiled with PlatformIO on the merged tree, **[stub]** driven in a browser
against a stubbed serial transport that fakes Marlin's `ok`, **[inferred]** reasoned from evidence but not
directly tested. **Nothing in this handoff was run on the machine.** Do not delete the markers — replace
them with an answer.

---

## 1. Where things stand

**Everything that was open in August is now in `main`, except four UI pull requests.** The six-PR
spincoater stack (#38 → #58), #70 (M754), #76 (measure liveness), the recipes / segment runner
(#82, #85, #88), the stub-DOM test harness (#87), the handoff and ODrive-config docs (#74, #75, #79,
#86), the run sheet with the restored J11 pinout image (#77), and the April Copilot G-code were merged
on 2026-09-14 as one consolidation, **PR #106**. **[source]**

**All of September's browser-UI work is also in `main`**, as **PR #107**: the sequencer homing gate,
argon purge around UV cure, the timeline canvas, the colour-blind-safe colour themes with a contrast
checker, immediate E-STOP abort of a running sequence, the Touch UI's Syringe block ported to the C
axis, the README's C-axis examples, and the no-Web-Serial banner. **[source]**

**The merged firmware compiles** (`pio run -e mega2560`: flash 30.1 %, RAM 44.7 %) **[build]** and
**has not been flashed.** The last hardware evidence is the 2026-08-17/19 sessions in the previous
handoff. Two of the consolidation's conflict resolutions are inside the spin cycle and must be
re-exercised before the August results are treated as covering `main` (§4, §5).

**The four UI pull requests #73, #78, #83, #84 are not merged and should not be merged as they are.**
They rebuild the UIs' connection layer for a serial-only page; September's `main` rebuilt the same
layer around the Pi bridge and the Process Sequencer. Only #84's verdict-by-message-class commit
applied cleanly and is in `main`. The rest is a redo on the current files, not a merge (§2, §5).
**[source]**

**The GitHub PR list is stale.** 23 pull requests still show as open: 19 of them are merged in
substance via #106 and four are the UI chain above. Nobody has closed anything yet.

**A second session later on 2026-09-14 added and merged five more small PRs (#111–#115)** — travel
limits, stamp geometry, a syringe prime button, and a test-harness fix that made `node tests/run.mjs`
runnable and exposed the live issue-#48 bug. Read **§2 (last subsection)**, **§4** and **§7** before
touching the UIs or the merge/test tooling; the three failing tests on `main` are pre-existing, not a
regression to chase.

---

## 2. What changed on 2026-09-14

### PR #106 — the older work, consolidated

Eleven merge commits, one cherry-pick and one doc fix; 53 commits, 36 files, +7397 / −662; original
authorship preserved, nothing squashed. Each merge commit's message records how its conflicts were
resolved. The ones that were decisions rather than mechanics: **[source]**

- **`measureSpeed()` in `M750.cpp` now returns a three-way result.** `main` had made it return `true`
  on a UI abort (`M410` sets `Spincoater::abortRequested`, added with the sequencer work in #98); the
  stack had made it return `true` on success and `false` on link loss / no samples. Both were kept:
  `MeasureResult {MEASURE_OK, MEASURE_ABORTED, MEASURE_FAILED}`. An abort prints `STATE:STOPPED` and
  `OK: ABORTED`; a failure prints the stack's `ERR: Measure phase aborted -- stopping spin`. The abort
  is also polled in the ramp-up loop.
- **`kill()` calls both spincoater hooks.** `Spincoater::safeStop()` (September; zero velocity, no-op if
  the ODrive serial was never begun) runs first, then the stack's `Spincoater::emergencyStop()` (IDLE
  twice, flushed, no reply read). Both are safe before `minkill()`'s `cli()`. `MarlinCore.cpp:914,920`.
- **`DispenseCureDemo1.gcode` is deleted**, as PR #39 intended. `main`'s 1 Sept rewrite had ported it
  to the C axis but still labelled `M42 P4 S0` as "UV ON" — the old active-LOW polarity. With the
  current active-HIGH relay modules that program would have ended with the lamp **on**. Restore it only
  with the polarity fixed.
- **The Controller's E-STOP message says "disconnect and reconnect; M999 cannot recover".** `main`'s
  text said "press Reset (M999)". On this board `M112` → `kill()` → `minkill()` → `for (;;)` with no
  KILL pin and `SOFT_RESET_ON_KILL` off, so the stack's wording is the true one (previous handoff §8;
  `HANDOFF.md` §7.6). The **Reset (M999)** button still exists in both UIs with a tooltip saying it
  clears only the softer "stopped" state.
- **`claude.md` merged both sides' gotcha lists** (main's 1–16, the stack's spincoater gotchas as
  17–27, September's homing-gate marker as 28), kept `main`'s C-axis `M201`/`M203`/`M92` examples,
  and took the stack's `M500`/`M501` warning — `EEPROM_SETTINGS` is off, so `M500` saves nothing and
  `M501` *resets* runtime tuning.

**Excluded — the UI chain #73 → #78 → #83 → #84** (`fix/64-ui-serial-reconnect`,
`fix/ui-identity-check-and-telem-log`, `fix/48-program-runner-ok-attribution`,
`fix/47-ui-error-markers`). A trial merge produced 13 conflict blocks across the two HTML files, and
the parts that auto-merged would have replaced `sendCmd()` / `disconnect()` with serial-only versions,
breaking the bridge transport. The `ok`-ledger (#83), the M115 identity check (#78) and the
lost-device recovery (#73) are all still wanted; they have to be re-done on top of the sequencer's
`seqCmd` / `seqOnOk` engine and the bridge transport. **[source]**

### PR #107 — September's HTML work

Seven commits from the unpushed local branch `claude/sequencer-homing-argon-uv-284459` plus three
edits that had been sitting uncommitted in worktrees. The Touch UI's Syringe block is now identical to
the Controller's: height slider with Lower / Raise, plunger jog slider (C 0–135), dispense and
pullback in mL through a hand-measured mm-per-mL calibration, relative `C` moves with no `G92`, raise
back to `B0` at the end, and the jog-feed / M203 fields relabelled E → C. Before this the Touch
block sent `G92 E0` / `G1 E…`, which the firmware has silently ignored since the K-axis conversion
(gotcha #1) — **the Touch Syringe block has never dispensed anything on the current firmware.**
**[source]**

The owner resolved the merge of `main` into that branch by keeping both sides of every conflict.
That left two `emergencyStop()` definitions in `RMR_Touch.html` (the second, without the sequencer
fault call, won — so E-STOP would not have aborted a running sequence), two Reset buttons in each UI,
contradictory `M500`/`M501` lines in the README and duplicated list numbers. Commit `3a41d35` fixed all
six spots; the E-STOP path was re-checked **[stub]**. The technique that found it is in §7.

### Later on 2026-09-14 — five more PRs merged (#111–#115)

A second session on the same day squash-merged five small PRs into `main` (newest first): **#114**
`ad81a97`, **#113** `8de15e8`, **#115** `ce3dd7b`, **#112** `23c2418`, **#111** `ed3d637`. Their
branches are still on `origin`. None was flashed or run on hardware; the UI ones were checked only
under the stub harness. What each changed, and the resulting current values:

- **#112 — travel limits (firmware).** `Configuration.h`: **C axis `K_MAX_POS` 135 → 125 mm**, **B axis
  `J_MAX_POS` 304 → 300 mm**. Soft-endstop-enforced, so **they do nothing until the Mega is reflashed.**
  **[source]**
- **#113 — stamp press coordinates.** #113 set the Stamp block's spincoater press point to
  **X122.3 Y27.3 Z155** (`stSX` / `stSY` field defaults + `numv` fallbacks; `stampForce` = 155),
  superseding #110's X123 Y18 Z163. **Superseded again 2026-09-17: both UIs and the layer G-code now
  use X111 Y23 Z167** (from a homed 6-axis readout; `stampForce` = 167). **[source]**
- **#114 — post-press retreat.** After a press, both UIs now retreat in three guarded **absolute** moves:
  `G1 Z75` (clear the spincoater, stay below the stowed lid) → `G1 Y0` (home to the **min Y limit
  switch**, clearing the syringe) → `G1 Z<safeZ>` (fully up, clear the stowed lid). The old code lifted
  a *relative* `Z-80` (landed at 75 only by coincidence of the press depth) and, in the Touch UI, went
  straight to fully-up while still over the spincoater. The absolute lift is the `stampLiftZ` field
  (default 75); the old "Post-press Y back-off" field/`stampBackY` id was removed from both UIs and from
  `SEQ_IDS`. **[stub]**
- **#111 — syringe C-axis prime button + 150 mL defaults.** Adds the "Initial purge (prime) +" button to
  the Syringe block (`syrPrimeNow` / `runSyringePrime`: pushes the plunger a set mL increment at the
  purge feed, no dwell/retract/lift, journaled by the Run Log), 150 mL catheter-tip syringe defaults, and
  opens all five sequencer cards by default. This is the branch flagged in the prior text as needing a
  defaults review; it was merged on the owner's explicit go-ahead. **[source]**
- **#115 — test harness fix (see §4).** The stub DOM now provides a canvas 2D context, `getPropertyValue`,
  `URLSearchParams` and the outer realm's typed arrays, so the UIs stop crashing at load and the suite
  actually runs. **[source]**

**#113 and #114 conflicted on merge** even though GitHub showed both `MERGEABLE` against the pre-merge
`main`: they edit adjacent lines of the Stamp block. After #113 landed, #114 was rebased and re-resolved
(keep #113's coordinates *and* #114's absolute-lift structure). See §7. **[source]**

---

## 3. Branch and PR state

**Merged into `main`:** #106 (`claude/older-work-consolidated`, 222189d) and #107
(`claude/september-html-work`, 14d9eb5). Both branches are still on `origin`.

**Merged into `main` later on 2026-09-14 (second session):** #111, #112, #113, #114, #115 as squash
commits (§2). Branches (`claude/…`: `dea-progress-tracker-e9a3c4`→#111 content, `axis-travel-limits`,
`stamp-press-coords`, `stamp-post-press-retreat`, `test-harness-canvas-stub`) are still on `origin` and
were not deleted. **#83 relates to the 3 failing tests those merges exposed** (§4, §5 item 6).

**Open on GitHub, merged in substance — close them:** #38, #39, #51, #56, #57, #58, #70, #71, #72,
#74, #75, #76, #77, #79, #82, #85, #86, #87, #88. Their heads are ancestors of #106's merge commits.

**Open on GitHub, superseded / needs redo:** #73, #78, #83, #84 (§2). #84's commit `29f3399` is in
`main` as `820713a`; the rest of #84 is the ledger it was stacked on.

**Local, in the owner's checkout (`C:\Users\anato\...\Robot-MakingRobot`):** **[source]**

- Ten untracked CAD files (`CAD/FilterSandwich_v20260908*`, `FilterSandwich_v20260909*`,
  `SyringeAxisEndstop*`, 1–10 Sept). They sit beside nine tracked CAD files, so they look intended
  for the repo. Not committed — the owner's call.
- Three git worktrees still show edits as uncommitted that are now merged (`rmr-controller-gui-tabs-0985cc`,
  `nostalgic-ptolemy-497dae`) or a stray preview-server `launch.json` (`fervent-curran-18055f`). Safe
  to discard. Local branches `claude/fervent-curran-18055f`, `claude/rmr-controller-gui-tabs-0985cc`,
  `claude/gracious-curie-365325`, `claude/nostalgic-ptolemy-497dae`, `claude/keen-snyder-8c8aa5` and
  `claude/sequencer-homing-argon-uv-284459` are fully merged (the last by squash, so `git branch
  --merged` does not list it) and can be deleted.
- **`gh` cannot create pull requests from the owner's Windows checkout.** Both stored credentials
  (Anatol-Gogoj and Pingwinos40) there are fine-grained tokens without "Pull requests: write"; pushes
  work under Anatol-Gogoj only. Fix on github.com (token permissions) or with a fresh `gh auth login`.
  `gh` is currently switched to Anatol-Gogoj there.
  **This does not apply to the Linux dev box** (`/home/anatol/Robot-MakingRobot`) used for the second
  2026-09-14 session: there `gh` is authed as **Pingwinos40** and `gh pr create` / `gh pr merge
  --squash` both worked — that is how #111–#115 were opened and merged (see the `gh pr edit` caveat in
  §7). **[source]**

---

## 4. Verified, and not

**Verified**

- The merged firmware builds for `mega2560`: flash 30.1 % (76 362 B), RAM 44.7 % (3 660 B). **[build]**
- Touch UI, Syringe block, with and without pullback, from the merged page: `G90 · G1 B<h> · M400 · G91 ·
  G1 C<mm> · M400 · [G1 C-<pull> · M400] · G90 · G1 B0 · M400`. Lower / Raise / Jog send `G1 B…` /
  `G1 B0` / `G1 C…` and are refused while unhomed. **[stub]**
- Touch UI E-STOP with a sequencer run in flight: the run is faulted at once with "emergency stop
  (M112)", `M112` is sent, one Reset button exists in the DOM. **[stub]**
- No `G92 E` / `G1 E` remains in either UI file. **[source]**
- Both UIs now dispatch spincoater `ERR:` / `OK:` lines by message class; the three substring false
  positives from the previous handoff's §2 (`CYCLE_COMPLETE_NO_HOME`, `HOME_SET_FAILED`,
  `HOME_SETTLE`) can no longer render as success. **[source]**

**Not verified**

- Nothing has been flashed since the merge. In particular the `measureSpeed()` merge and the `kill()`
  hook order are untested on hardware. Run-sheet Tasks 5, 6 and 8 are the quickest re-check.
- The `tests/` stub-DOM harness now **runs** on this Linux dev box — a portable Node v20 was installed
  to `~/.local` (see §7; the owner's Windows checkout still has no Node). `node tests/run.mjs` on `main`
  reports **12 passed / 3 failed** **[stub]**. The 3 failures are **not** harness noise and **not**
  something a new agent introduced — they are the live issue-#48 bug (§5 item 6): `ok attribution`
  (Controller + Touch) and `homing indicator` (Touch) assert the fixed behaviour, and `main` still
  advances the program / clears the homing indicator on a *foreign* `ok`. `spin-markers` (issue #47) and
  the run-log / syringe-dose checks pass. Still **[stub]** only — none of this ran on hardware.
- Before #115, that harness had never run at all: the UV/argon progress bar draws to a `<canvas>` in
  `seqInit`, and the stub DOM's missing `getContext` threw at load, taking every UI test down with it.
  So the prior handoff's "expected to fail" was really "never executed". #115 fixed the harness; the
  three real failures above are what was hiding behind the crash.
- `RMR_SegmentRunner.html`, `LayerCycle.gcode`, `LayerCycle.segments.gcode`, `SpinCoatUVCure.gcode` and
  `fullcode.gcode` have never been exercised on this firmware, and all five still drive the syringe with
  `G92 E0` / `G1 E…` (§5, item 3).
- The sequencer / theme commits from 11 Sept were not re-tested beyond loading the pages.

---

## 5. Do this next

Ordered. Items 2 and 4 rotate the chuck; **a person must be in the room, and must be asked explicitly.**

**1. Close the 19 merged pull requests** listed in §3, and decide #73 / #78 / #83 / #84 (close as
superseded, or leave open as the spec for the redo). Until then the open list misstates the state of
the repo.

**2. Flash `main` and repeat run-sheet Tasks 5, 6 and 8.** Task 5 (normal G-code streams at 250000
baud with `EMERGENCY_PARSER` on) because the RX hot path is unchanged but the binary is new; Task 6
because `kill()` now runs two spincoater hooks; Task 8.2 / 8.3 because the measure-phase result was
re-plumbed. Then `M750 S1000 D10 A3 C3 H1` once, expecting the same `Samples≈100`, `MeanRPM≈1010`,
`OK: INDEX_COMPLETE`, `OK: CYCLE_COMPLETE` as 2026-08-19. New since then: **a Process Sequencer Stop
during the measure phase should print `STATE:STOPPED` and `OK: ABORTED`** and leave the board alive;
that path has never run on hardware.

**3. Port the E-axis syringe moves before anyone runs a layer program.** `fullcode.gcode:28-31`,
`LayerCycle.gcode:30-33`, `LayerCycle.segments.gcode:85-88`, `RMR_SegmentRunner.html:1640-1641` and
`SpinCoatUVCure.gcode` (six places) all send `G92 E0` / `G1 E-<n>`. The firmware ignores them without
an error, so a "dispense" step dispenses nothing and the cycle continues. The idiom is
`G91` / `G1 C<mm> F300` / `G90` for a relative push (+C dispenses); never `G92 C0` on the homed axis.
`fullcode.gcode` is described as the production DEA layer program — it is the one that matters.

**4. Re-run T3 (the physical-mark check) once after the flash**, exactly as the previous handoff's
§6 item 3, to confirm the datum path survived the merge. Expect `HomeSettleErr` inside 1.08°.

**5. The UI serial contract, second half (issue #47).** Done: `ERR:` / `OK:` by message class; any
`ERR:` sets the error phase; the Touch toasts errors. Still open, in both files: `WARN:` lines are
plain grey console text (thirteen datum-integrity messages land there); `STATE:HOME_SETTLE`,
`MEASURE_LINK_LOST`, `DECEL_LINK_LOST`, `DECEL_STALL` have no phase (their `ERR:` lines now show, so
nothing is stuck green); `INDEX_SETTLE` is a dead key; and the new `STATE:STOPPED` / `OK: ABORTED` pair
is unmapped, so after a sequencer Stop mid-spin the panel keeps showing "Measuring speed…".

**6. Redo #48 (Program Runner `ok` attribution) on the current UI**, then #78's M115 identity check,
then decide whether #73's reconnect logic adds anything to September's device-lost handling. All
three are UI-side and need no hardware. The Process Sequencer already keeps one command in flight and
pauses auto-report; the Program Runner still advances on any bare `ok`, auto-report `M114` included.
There is now a **runnable regression test** for this: since #115, `node tests/run.mjs` exercises
`ok-attribution` and `homing-indicator` against `main` and they fail (§4) — the failure trace points
at the `lastG28Pending` boolean in `RMR_Touch.html`'s `ok` handler (clears homing on the first `ok`
while a G28 is merely pending), the exact pattern the fix must replace with per-command attribution.
**PR #83 is that fix, but is a serial-only redo and cannot be merged as-is** (§2, §8 item 2): re-apply
its `ok`-ledger idea to the current Pi-bridge code, then run the suite green.

**7. Decide the Reset (M999) button.** It cannot do what its label suggests after an E-STOP. Either
remove it from both UIs or relabel it for the "stopped" state it actually clears. `claude.md` gotcha #6
and the README are already correct.

**8. Decide `DispenseCureDemo1.gcode`.** Deleted in #106 (§2). If it is wanted, restore it from
`4ef31d7` and fix the `M42 P4` polarity first.

**9. Decide the ten CAD files** in the owner's checkout (§3).

**10. T5 / run-sheet Task 7.4–7.7 — still held by the owner**, deliberately, for the reason given in
the previous handoff. Unchanged.

**11. #46 — the encoder-reference bench question — is unchanged and still gates #52, #54, #55 and
half of #45.** `M754` is now in `main` for exactly this: it dumps the ODrive encoder configuration over
Serial2 as `echo:SPIN CFG:` lines, so the question can be answered without the ODrive's failed USB link.

---

## 6. Findings that must not be re-derived

- **`M112` is terminal on this board.** `kill()` → `minkill()` → `for (;;) hal.watchdog_refresh()`; the
  `hal.reboot()` branch needs `HAS_KILL` or `SOFT_RESET_ON_KILL`, and neither is defined. `M999` cannot
  recover it; a DTR toggle (reconnect) or power cycle can. Settled in `HANDOFF.md` §7.6 and on the bench
  2026-08-19; September's `main` had drifted back to "press M999". **[source]** **[bench]**
- **`measureSpeed()` has three exits, not two** (§2). Anyone touching `M750.cpp` should read the enum
  comment before "simplifying" it back to a bool — that is exactly the conflict the merge resolved.
- **`kill()` runs `safeStop()` then `emergencyStop()`.** Both are safe when the ODrive serial was never
  begun; `emergencyStop()` must never call `idle()` / `safe_delay()` (previous handoff §8). **[source]**
- **The four UI PRs conflict architecturally with September's `main`, not textually.** Do not try the
  merge again; redo the features (§2, §5 item 6). **[source]**
- **The Touch UI's Syringe block had been dead since the K-axis conversion** (§2). Any bench note from
  before 2026-09-14 that says the Touch UI "dispensed" was reporting a no-op. **[source]**
- **`fullcode.gcode` and the LayerCycle family still use the E axis** (§5 item 3). **[source]**
- **The AVR toolchain fails on paths over 260 characters** with `common-dependencies.h: No such file`
  from `avr-g++`, before any real compile. A long worktree path (e.g. under `AppData\Local\Temp\claude\…`)
  is enough. Build from a short path. **[build]**
- **Neither stored `gh` credential can create pull requests on the owner's Windows checkout** (§3);
  `gh pr create --web` still works there and opens the prefilled form (that is how #106 and #107 were
  opened). The Linux dev box is not so limited — its `gh` (Pingwinos40) opened and merged #111–#115
  from the CLI (§3, §7). Check which machine you are on before assuming.

---

## 7. Traps

- **"Keep both sides" is not a conflict resolution.** The merge of `main` into #107 kept both sides of
  all six blocks. Effects: a duplicated JavaScript function where the *later* definition silently wins
  (the sequencer's E-STOP fault call disappeared), duplicated buttons, a README that said both "M500
  saves to EEPROM" and "M500 is unavailable". GitHub reported the branch as mergeable throughout.
  **Check any hand-resolved merge with**
  `git merge-tree --write-tree <parent1> <parent2>` **and** `git diff <that-tree> <merge-commit>`:
  the diff is exactly the human's resolution, and a diff that is only deleted `<<<<<<<`/`=======`/
  `>>>>>>>` lines means nothing was chosen. **[source]**
- **Squash merges hide merged branches.** `git branch --merged` does not list a branch whose commits
  reached `main` by squash (e.g. `claude/sequencer-homing-argon-uv-284459`), and `git branch -r
  --no-merged` lists 28 remote branches of which most are merged in substance. Use the PR state on
  GitHub, not ancestry, to decide what is outstanding.
- **`gh auth switch` also switches git's push credential** (the `gh auth git-credential` helper). A
  push that worked under one account can be refused under the other.
- **`direction: rtl` on a vertical `<input type=range>` flips which end is the minimum.** The Touch
  syringe slider used it and read "304 top / 0 btm" while the Controller read "0 up / 304 down". #107
  removed it so both sliders put B = 0 (nozzle up) at the top. **[source]**
- **`WARN:` still goes nowhere in the UI** (§5 item 5). Read the console.
- **Two PRs that touch adjacent lines of the same block both show `MERGEABLE`, then the second conflicts
  after the first lands.** #113 and #114 both edited the Stamp block; GitHub reported both clean against
  the pre-merge `main`. Merging #113 made #114 `CONFLICTING`. The fix is not `--force`: rebase the second
  branch onto the new `main`, resolve keeping *both* intents, re-run `node tests/run.mjs`, force-push,
  then merge. Merge the independent PRs first and leave same-block PRs for last. **[source]**
- **`gh pr edit` fails on this repo** with a GraphQL error about *Projects (classic) … projectCards*
  (a deprecated field `gh` still queries). Editing a PR title/body goes through the REST API instead:
  `gh api -X PATCH repos/Anatol-Gogoj/Robot-MakingRobot/pulls/<n> -f title=… -f body="$BODY"`. `gh pr
  create` and `gh pr merge --squash` work fine. **[source]**
- **No Node by default on this Linux dev box**, so `node tests/run.mjs` is "command not found" until you
  install one. There is no root: a portable build was unpacked to `~/.local` (`~/.local/bin` is already
  on `PATH`), so a bare `node` works now — but a fresh machine needs the same one-time step. **[source]**

---

## 8. Decisions not to relitigate

The previous handoff's §9 stands. Added on 2026-09-14:

1. **The older work was merged as one consolidation (#106), not bottom-up.** Run-sheet Task 11 and
   the stack's "forced order" were about keeping bases straight; merging the tip carried the whole
   chain with authorship intact. Done; do not re-open.
2. **The UI chain (#73, #78, #83, #84) is a redo, not a merge** (§2).
3. **The E-STOP message says reconnect; M999 is not a recovery** (§6).
4. **`measureSpeed()` returns `MeasureResult`** (§2).
5. **`DispenseCureDemo1.gcode` stays deleted** unless restored with the polarity fixed (§5 item 8).
6. **PR descriptions open with a `TL;DR:` paragraph and end on the verification notes** — no
   attribution footer, links or emojis at the bottom. Commit messages keep their trailers.
7. **A hand-resolved merge is checked with `git merge-tree` before it is pushed** (§7).

---

## 9. Open questions

Carried forward from the previous handoff's §10, still unanswered: 1 (USB cable swap), 2
(`chrome://device-log`), 4 (real spin-down time), 5 (brake resistor), 6 (`procedure_result` on a good
`M752`), 7 (thermistor vs homing failures), 8 (#61, UV lamp after a power cycle), 9 (#68, the USB
isolator), 10 (angular accuracy the process needs), 11 (`H` default), 13 (named recipes — note #88
built them, unexercised), 14 and 15 (segment-runner semantics and the second copy of the process).
Answered: 3 (spins longer than 3 s complete — 2026-08-19) and 12 (merge policy — all at once, 2026-09-14).

New:

### For the bench
16. **Does a Process Sequencer Stop during `M750`'s measure phase print `STATE:STOPPED` + `OK: ABORTED`
    and leave the board alive?** Never run on hardware (§5 item 2).
17. **Does the merged `kill()` still disarm the ODrive within one poll interval** with `safeStop()`
    running first? Run-sheet Task 6.5 again.
18. **What does `M754` print on this ODrive?** It answers #46 without the ODrive's USB link.

### For the owner
19. **Which redo comes first: #48 (`ok` attribution), #78 (identity check) or #73 (reconnect)?**
    §5 item 6 suggests that order.
20. **Keep, remove or relabel the Reset (M999) button?** (§5 item 7)
21. **Restore `DispenseCureDemo1.gcode` with the polarity fixed, or leave it deleted?** (§5 item 8)
22. **Commit the ten CAD files?** (§3)
23. **Should the 19 merged pull requests be closed with a note pointing at #106?** (§5 item 1)

---

## 10. Working agreements

From the previous handoffs, still in force: one issue → one branch → one PR; correctness over
efficiency; every firmware change builds before push; adversarial review before commit; every PR body
carries bench steps; **no motion commands without a person in the room, asked explicitly**; say what
you are about to run before running it; find the log before changing anything.

**Nothing merged on 2026-09-14 had a fresh adversarial review.** #106's firmware conflict resolutions
were compiled and read, not reviewed by a second lens; #107's conflict fix was checked in a stubbed
browser. Treat the merged spin cycle as "written and compiled" until Task 5/6/8 pass again.

Added:

- **PR descriptions follow the house style** (§8 item 6).
- **Hand-resolved merges get the `git merge-tree` check** (§7) before push, and the check goes in the
  PR body.
- **Anything that touches `spincoater.cpp`, `M750.cpp` or the two UI files' serial parsing cites
  function names, not line numbers.** The line citations in `claude.md`'s spin-coater section were
  taken at the stack tip and have drifted with every merge since.

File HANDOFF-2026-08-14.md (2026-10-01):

# HANDOFF — 2026-08-14

> **Superseded by `HANDOFF-2026-08-19.md`, and that by `HANDOFF-2026-09-14.md`.** The work described here merged into `main` on 2026-09-14 (PR #106).

**Supersedes** `HANDOFF.md`, which lives on branch `fix/44-feedback-numeric-validation`. Read that
one for the reasoning behind the six-PR stack; its central claims are now out of date and §2 below
says exactly how.

Claims here are marked by how they were established: **[bench]** observed on the hardware,
**[source]** read out of this repo, **[inferred]** reasoned from evidence but not directly tested.
Do not delete those markers — replace them with an answer.

---

## 1. Where things stand

**The bench is real now.** There is a provisioned Ubuntu laptop next to the machine, on the lab
WireGuard mesh, with a working toolchain, both USB devices under stable names, and a remote desktop.
Firmware can be built, flashed and driven remotely.

**The six-PR stack is flashed and running on hardware for the first time.** `EMERGENCY_PARSER` —
the single highest-consequence unverified change in it — is verified: the gantry homes, moves and
streams G-code correctly at 250000 baud. **[bench]**

**The leading root-cause hypothesis was wrong.** The encoder *is* index-referenced. Three actual
faults were found instead, and two of them have fixes written but never run. See §2.

**Nothing from the original stack has merged.** Merge order is still forced and unchanged.

---

## 2. What changed since the previous handoff

### The encoder is index-referenced. That hypothesis is dead.

`HANDOFF.md` §2 named "the encoder was never index-referenced for position" as the leading
candidate, and said four issues would need re-planning if it were true. It is not true. **[bench]**

```
config.gpio10_mode                              = 0      (DIGITAL, not AUTO)
axis0.pos_vel_mapper.config.use_index_gpio      = 1
axis0.pos_vel_mapper.config.index_offset        = 0.0
axis0.pos_vel_mapper.config.index_offset_valid  = 1
inc_encoder0.config.cpr                         = 8192
```

The original grep that suggested otherwise was searching *this repo*. The settings were configured
on the hardware years ago and live in the ODrive's NVM. See `ODRIVE_CONFIG.md` (PR #74).

So **#45, #52, #54 and #55 keep their premises.** The Tier 3 ordering in the old handoff stands.

### But the reference is modulo ONE TURN, which nobody expected

The index search corrects the fractional position within a revolution and leaves the integer turn
count accumulating, because `pos_vel_mapper.config.circular` is `False`. **[bench]**

Two searches, several hand-turns apart:

| Search | `pos_estimate` after | Fractional part |
|---|---|---|
| first | `0.38` | **0.38** |
| second | `10.375702` | **0.3757** |

Agreeing within 1.8°, against a measured settle error of 0.86°.

**This is the single most important finding in this document.** It explains why
`index_offset_valid: True` and a `pos_estimate` that never returns to zero are not a contradiction,
and it is the whole of #55.

Evidence is two data points. A third would put it beyond doubt and costs one more index search.

### Three real faults, replacing the one that wasn't

**1. A floating thermistor input.** `ODriveError.THERMISTOR_DISCONNECTED` disarmed the axis
mid-procedure, giving `procedure_result = 3 (DISARMED)` on every index search. `clear_errors()` did
not clear it — the condition was live. The D5312s has no thermistor and never did; the input floated
and drifted across the disconnect threshold, which is why the fault was **intermittent**. **[bench]**

**This is the leading explanation for the original "the spin coater does not home properly"
report.** An intermittent fault that disarms the axis mid-search produces exactly that symptom.
**[inferred]** — plausible and well-supported, but not yet demonstrated by a long run of successful
homes. Disabled on the hardware 2026-08-13.

**2. `boot()` declared a datum from a search that never happened.** With the thermistor fault
active, `boot()` printed `datum established at the index mark` over an index search that had
disarmed. `InitialPos=-0.73` was the *pre-search* position, and `BootSettleErr` never printed at
all. **[bench]** Three silent failure paths, plus a fourth design bug — the settle targeted absolute
zero, which is only ever correct when the rotor happens to be near turn zero. Fixed in PR #72,
**never run**.

**3. The >1-turn guard compared absolute multi-turn positions.** It refused every post-spin home on
a healthy machine — `Position 10.38 is >1 turn from home datum 7.44` describes two positions 21°
apart. **[bench]** Fixed in PR #71, **never run**.

---

## 3. How to reach the machine

| | |
|---|---|
| Bench laptop | on-site laptop, Ubuntu 26.04, GNOME 50 on **Wayland** |
| Repo on laptop | `~/Robot-MakingRobot`, currently on `fix/69-boot-honest-index-search` |
| Mega | `/dev/rmr-mega` — Arduino Mega 2560, `2341:0042` |
| ODrive | `/dev/rmr-odrive` — ODrive S1, `1209:0d32` |

Host name, network address, account and remote-desktop details are kept off this public
repo; the owner holds them privately.

Full detail in `bench-laptop/BENCH_LAPTOP_SETUP.md`. Its §7 records every failure hit while building
it and is worth ten minutes.

**Sending G-code over SSH** — `stty` cannot set 250000 baud (non-standard, needs `termios2`). Use
pyserial from PlatformIO's venv:

```bash
~/.platformio/penv/bin/python -c "
import serial,time
p=serial.Serial('/dev/rmr-mega',250000,timeout=0.3); time.sleep(3); p.reset_input_buffer()
p.write(b'M115\n')
for _ in range(60):
    l=p.readline()
    if l: print(l.decode(errors='replace').rstrip())
"
```

Opening the port resets the Mega via DTR. Harmless — nothing moves on boot — but it destroys the
in-RAM datum.

---

## 4. Branch and PR state

### The original stack — unchanged, still unmerged, order still forced

`main` ← **#38** ← **#39** ← **#51** ← **#56** ← **#57** ← **#58**

`fix/44-feedback-numeric-validation` is the stack tip. It is what is flashed on the board today.

### New since

| PR | Base ← Head | What | Built? | Run on hardware? |
|---|---|---|---|---|
| **#70** | `fix/44` ← `feature/m754-encoder-config-dump` | `M754` read-only ODrive config dump over UART | yes | **yes** |
| **#71** | `fix/44` ← `fix/55-normalise-datum-into-encoder-frame` | #55: normalise the datum instead of refusing | yes | **no** |
| **#72** | `fix/55` ← `fix/69-boot-honest-index-search` | #69: `boot()` honest index search | yes | **no** |
| **#73** | `main` ← `fix/64-ui-serial-reconnect` | UI recovers from a lost serial device | n/a | partly |
| **#74** | `main` ← `docs/odrive-config` | `ODRIVE_CONFIG.md` | n/a | n/a |

**#70 and #71 are siblings, not stacked** — both base on `fix/44`. They touch disjoint files
(`M754.cpp`/`gcode.*`/`features.ini` vs `spincoater.cpp`) so either can merge first. **[source]**

The board currently runs `fix/69-boot-honest-index-search` **merged locally with
`feature/m754-encoder-config-dump`** — i.e. stack tip + #71 + #72 + M754. Build `Aug 13 2026
19:45:48`, flash 30.4%, RAM 44.4%. **[bench]**

Merged today: **#60**, **#63** (bench laptop kit). Run sheet pushed on
`claude/machine-debug-run-sheet-01fa35`, **no PR opened yet**.

---

## 5. Verified on hardware, and not

### Verified **[bench]**

- **Run sheet Task 5** — `G28` homes in the correct sequence, all axes move correctly, `M119` reads
  all five endstops, serial solid at 250000 baud with `EMERGENCY_PARSER` compiled in. The largest
  risk in the stack, cleared.
- **Task 2 §2.1–2.5** — full ODrive config read, twice, over two independent transports
  (`odrivetool`/USB and `M754`/UART) with matching results.
- `M753` — 24.07–24.12 V in 4–5 ms, repeatedly.
- `M754` — every value matched `odrivetool`.
- Index search completes and settles when the datum is in-frame: `HomeSettleErr=0.86 deg`,
  `OK: INDEX_COMPLETE`.
- Bench laptop survives a reboot with mesh, autologin and RDP all returning unaided.

### Not verified

- **PR #71 and #72 — the two fixes written yesterday. Built, never run.** This is the top of the list.
- Task 5.4 (`DemoProgram.gcode` line-loss count) and 5.5 (jog flood).
- Tasks 6–10 — the spincoater PR validation checklists for #51, #56, #57, #58.
- Task 12 (relays after the module swap), Task 13 (servo shudder).
- Whether disabling the thermistor actually eliminates the intermittent homing failures over a long
  run.

---

## 6. Do this next

All of it rotates the chuck. **A person must be in the room.**

**1. PR #72 case 2 — the highest-value single test.** The rotor is currently at `pos_estimate ≈
10.376`, many turns from zero, which is exactly the condition the old `t 0 0.0` settle target could
never handle. Reset the Mega (reconnecting the GUI does it via DTR), then:

```gcode
M752
```

Expect `BootSettleErr` to **print** — it never has — and the settle to complete in about a second
rather than crawling into the 8 s timeout.

**2. PR #71 — the post-spin home that used to be refused outright.**

```gcode
M751
M750 S1000 D10 A3 C3 H0
M752
```

Expect `DatumNormalised turns=<~160>`, then `HOME_SETTLE`, then `OK: INDEX_COMPLETE`.

**3. The `DEG` invariance check — do not skip this one.** Normalising the datum is only legitimate
because `fmod((pos − _homePos) × 360, 360)` is invariant under dropping whole turns. Confirm the
reported `DEG` is unchanged across a normalisation. **If `DEG` shifts, PR #71 is wrong even though
homing completes.**

**4. Third data point for the modulo-one-turn finding.** Index search, record the fractional part of
`pos_estimate`, hand-turn a couple of turns, index search again, compare. `M752` refusing on the
guard is fine — the search runs *before* the refusal, so the position still tells you what you need.

**5. Honest-failure check.** Disconnect the encoder index wire, reset the Mega, `M752`. `boot()` must
report *no valid datum* rather than announcing one, and the following `M752` must refuse rather than
settle to garbage.

Then merge, bottom-up, in the forced order, and resume Tasks 6–10.

---

## 7. Findings that must not be re-derived

- **The index reference is modulo one turn.** §2. Everything about datum comparison follows from it.
- **`pos_estimate` is a continuous multi-turn accumulator** (`circular: False`). It never returns to
  zero and is not supposed to.
- **The ODrive does not index-search on power-up** (`startup_encoder_index_search: False`), so the
  absolute frame is undefined after every ODrive power cycle until something crosses the index.
  `index_offset_valid: True` means "we know where the index is", not "we know where we are".
- **The ODrive config exists only in NVM.** `ODRIVE_CONFIG.md` records the load-bearing values, but
  it is not a backup. Run `odrivetool backup-config` before touching ODrive firmware.
- **`axis0.pos_estimate`**, not `axis0.pos_vel_mapper.pos_estimate`. The latter is `invalid property`.
- **`stty` cannot set 250000 baud.** Use pyserial.
- **The ODrive answers a bad property path with the literal string `invalid property`**, not silence.
  A wrong path and a dead link look different — deliberately.

---

## 8. Traps

- **A serial port has exactly one holder, and Linux will not enforce it.** Chrome, picocom, avrdude
  and odrivetool all want the same devices. Observed with Chrome *and* picocom holding
  `/dev/rmr-mega` simultaneously, each getting fragments. **Disconnect the UI before any upload.**
- **After flashing, the UI cannot reconnect** until PR #73 lands; reload the page. If the device
  does not reappear, unbind/rebind it:
  ```bash
  DEV=$(basename $(dirname $(grep -l 2341 /sys/bus/usb/devices/*/idVendor)))
  echo "$DEV" | sudo tee /sys/bus/usb/drivers/usb/unbind; sleep 2
  echo "$DEV" | sudo tee /sys/bus/usb/drivers/usb/bind
  ```
- **Both devices are CDC-ACM and swap numbers freely.** The ODrive has held `ttyACM0` — the Mega's
  old number. Always address them as `/dev/rmr-mega` and `/dev/rmr-odrive`; the udev rules are keyed
  on serial number for this reason (#65).
- **The ODrive USB link runs without its isolator** (#68). If `odrivetool` reports
  `LIBUSB_ERROR_IO` or dmesg shows `can't set config #1, error -71`, that adapter is back in the
  cable. The UART link is unaffected either way — `M753` and `M754` still work.
- **A cold ODrive emits garbage.** `M753` immediately after powering the rig returned 13 bytes of
  binary and 26 stale bytes. Wait and retry before concluding anything.
- **`ok` from Marlin does not mean the command succeeded.** Read the terminal marker.
- **Marlin compiles only sources listed in the feature's `build_src_filter`.** A new G-code file
  needs registering in `ini/features.ini` as well as declared and dispatched, or it fails at *link*
  time with `undefined reference`.

---

## 9. Decisions not to relitigate

The eight in `HANDOFF.md` §4 all still stand. Added since:

| # | Decision | Reason |
|---|---|---|
| 9 | **Normalise the datum into the current frame; do not merely relax the comparison.** | Comparing modulo one turn alone would leave `t 0 <_homePos>` commanding a move hundreds of turns long — the doomed crawl the original guard existed to prevent. PR #71 fixes comparison and target together. |
| 10 | **No write passthrough to the ODrive from G-code.** | `M754` is read-only by construction. A general passthrough would put `w axis0.requested_state 8` one text box away from spinning the chuck, on a machine whose mechanical E-stop is still #20. |
| 11 | **The touch UI auto-reconnects; the controller UI does not.** | The controller is open during uploads, and an automatic re-attach would race avrdude for the port. Recorded in the file so the asymmetry is not "fixed" later. |
| 12 | **Remote desktop shares the existing session; never per-user sessions.** | One serial port, one holder. Two desktops means two browsers means a fight over `/dev/rmr-mega`. |

---

## 10. Open questions

### For the bench

1. **Does disabling the thermistor actually stop the intermittent homing failures?** The mechanism is
   understood; the cure is not yet demonstrated over a long run.
2. **Third data point for modulo-one-turn.** §6 item 4.
3. **Does `DEG` survive a normalisation?** §6 item 3. This validates PR #71's premise.
4. **Time a real spin-down from `M750 S5000 ... C1`** — PR #57's thresholds are still guesses.
5. **Does a visibly-good `M752` ever report a non-zero `procedure_result`?** PR #56 hard-fails on it.
6. **Is a brake resistor fitted?** Still unanswered from the original handoff. Gates the e-stop
   design (#40, decision 1).
7. **#61 — the UV lamp stays on after a power cycle.** Filed by the owner, not investigated here.
   Safety-relevant: an unattended UV source that survives a power cut. Relay polarity and boot-time
   pin state are the obvious suspects (gotcha #13).
8. **Was the ODrive's USB isolator solving an observed problem, or added speculatively?** (#68)
   Decides whether to replace it, drop it, or leave USB disconnected in normal operation.

### For the owner

9. **What angular accuracy does the DEA process need?** Stated as roughly ±2°, design-dependent.
   Present evidence: ~1.5° repeatability between index searches, 0.86° settle error — so plausibly
   already inside it, but n=2.
10. **Does the process need the chuck at a known angle after every layer, or only at defined
    points?** Unanswered from the original handoff. Decides whether `H` should default to 0.
11. **Merge policy** — all at once after the bench signs off, or incrementally.
12. **#62** — sequential step control in the UI. Filed by the owner, unscoped here.

---

## 11. Working agreements

From the original handoff, still in force: one issue → one branch → one PR; correctness over
efficiency; every firmware change builds before push; adversarial review before commit; every PR
body carries bench steps.

**Note that PRs #70–#74 did NOT get an adversarial multi-lens review.** Each says so in its own body.
They are small, mostly read-only, and #70 has run on hardware — but that is not the same thing, and
the process exists because three of the four original fix PRs had a self-inflicted regression caught
by exactly that review.

Added:

- **No motion commands without a person in the room.** `G28`, `G1`, `M280`, `M750`, `M752` and any
  G-code program. The machine has a 5000 RPM chuck, a UV lamp and a solenoid, and **no mechanical
  E-stop** (#20).
- **Say what you are about to run before running it**, for anything that touches the machine.
- **Find the log before changing anything.** Nearly every failure in this project has been silent or
  actively misleading — a hang instead of an error, a green success on a red failure, packets leaving
  with nothing coming back. Each was settled by one line of log after an hour of guessing.

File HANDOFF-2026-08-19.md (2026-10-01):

# HANDOFF — 2026-08-19

> **Superseded by `HANDOFF-2026-09-14.md`.** Everything open in this handoff except PRs #73 / #78 / #83 / #84 merged into `main` on 2026-09-14 (PR #106); §3 (USB fault) and §4 (GUI problem) are carried forward unchanged.

**Supersedes** `HANDOFF-2026-08-14.md` (PR #75). That document's §2 finding — the index reference is
modulo one turn — is now confirmed on hardware and is load-bearing for everything below. Its §6
"do this next" list is **done**; §2 here says what came of it.

Claims are marked by how they were established: **[bench]** observed on the hardware,
**[source]** read out of this repo, **[inferred]** reasoned from evidence but not directly tested.
Do not delete those markers — replace them with an answer.

---

## 1. Where things stand

**The two unrun fixes are no longer unrun.** PR #71 and #72 were both exercised on hardware on
2026-08-17, including on the condition that actually distinguishes them from the bug they fix. Both
pass. **[bench]**

**A new firmware bug was found, and it was blocking every real spin.** No `M750` with `D > 3` could
complete — the measure phase aborted at exactly 3.000 s every time, claiming a dead link that was
demonstrably alive. Fixed in PR #76, flashed and confirmed on 2026-08-19. **[bench]**

**The bench laptop cannot reliably drive the machine from Chrome.** The GUI connects, receives
Marlin's `start`, then loses the device. Cause not established. `pyserial` over SSH works every time
on the same device at the same baud. **[bench]**

**The Mega's USB link is intermittently faulty.** 44 spontaneous re-enumerations since the laptop
booted on 2026-08-13, several with nobody in the building. This is the top hardware item, and it may
share a root cause with the GUI problem. **[bench]**

**Nothing has merged.** Twenty PRs are open. Merge order in the original stack is still forced.

**The process program is in version control as of 2026-08-19.** It was not before. `DemoProgram.gcode`
on `main` is the 2026-08-05 pick-and-place with no `M750`/`M751`/`M752` in it at all, and different
coordinates besides; the program that actually encodes the process lived only on the bench laptop.
It is now `LayerCycle.gcode` (PR #82), executable lines unchanged, comments corrected to match the
code. **Treat git as the source of truth from here** — a bench-only edit is one wiped home directory
away from being the only copy, and it is the artifact #62's runner is built to parameterize.

---

## 2. What the 2026-08-17 bench session established

### PR #72 — boot() settles to the nearest index mark. Confirmed.

`BootSettleErr` **printed for the first time in this machine's history.** Under the old code it never
printed, because the settle never converged.

The run that matters was taken with the rotor at `InitialPos=3433.00` turns. **[bench]**

| | Old code (`t 0 0.0`) | New code (`roundf(p0)`) |
|---|---|---|
| Settle target | 0.0 | 3433 |
| Distance to travel | 3433 turns | ~0.4 turns |
| Time at `vel_limit` 0.25 turns/s | **3.8 hours** | 1.6 s |
| Outcome | killed by the 8 s watchdog | `BootSettleErr=0.00 deg` at 2.2 s |

**An earlier run the same day also passed but proved nothing**, because an ODrive power cycle had
zeroed `pos_estimate` — with the rotor near zero, `roundf(p0)` is 0, which is exactly what the old
code did. Only the 3433-turn run discriminates. If this is ever re-tested, **reset the Mega, not the
ODrive**: `pos_estimate` lives in the ODrive, and a DTR reset of the Mega leaves it intact.

### PR #71 — datum normalisation. Confirmed, including the invariance it rests on.

First successful post-spin home this machine has produced: `DatumNormalised turns=-206
newHomePos=198.00`, then `HomeSettleErr=0.88 deg`, `OK: INDEX_COMPLETE`. The old guard would have
refused this exact case with *Position 198 is >1 turn from home datum -8.00*. **[bench]**

**The DEG-invariance gate passed.** This was the one test that could have invalidated a fix that
otherwise appears to work:

| Moment | `POS` | `DEG` |
|---|---|---|
| `M751` — datum set | 107.00 | **0.00** |
| after spin, `M752` normalises `turns=-104` to `newHomePos=211.00` | 211.00 | **359.95** |

The datum moved by **exactly 104 whole turns** and the reported angle for the same physical position
came back **0.05° from zero**, against a 2° threshold. Dropping whole turns does not move the
angular frame. **[bench]**

**The physical-mark corroboration was lost.** Someone powered the ODrive down overnight; the rotor
drifted ~30° while unpowered and free. The numeric result stands on its own, but the mark check is
cheap and worth redoing — see §6.

**Redone and passed on 2026-08-19** — the mark returned. See §6.

### New bug: the measure phase aborted on a healthy link, every time

`measureSpeed()` armed `lastTelemOkTime` once on entry (`M750.cpp:83`) and never refreshed it. The
loop does its own `feedback()` calls and never reaches `spinTelemetry()`, the only other place that
refreshes it. The 3-second dead-link watchdog therefore fired **exactly 3000 ms into MEASURING,
regardless of link health.** **[source]** + **[bench]**

Observed four times: twice at `D10`/1000 RPM, once at `D30`/5000 RPM, and once during the T3 run
where the abort timestamped at 6.31 s against `MEASURING` at 3.30 s — 3.01 s. The link was provably
fine: `RAMP_UP` completed each time, and its exit condition needs live telemetry; `M752` then ran
clean over the same UART seconds later.

This is a regression introduced alongside the watchdog itself (issue #42, PR #57). Fixed in PR #76.

### `M750`'s `D` parameter excludes the ramps

`D` is the **hold/measure duration only** — `M750.cpp:11`. **[source]** The 14 August handoff
predicted `turns=~160` for `M750 S1000 D10 A3 C3` assuming `D` covered the whole cycle. It does not;
a complete cycle is ~217 turns.

Corroborated at the bench: a run truncated by the 3 s abort banked **104 turns** against a predicted
100 — 25 ramping up, 50 during the 3 s measure, 25 ramping down. **[bench]**

### The settle error you see is the tolerance, not the machine

Eight settle errors were recorded across the session: 0.09, 0.19, 0.29, 0.37, 0.88, 0.93, 0.95 and
1.00 degrees. All under 1.08°, and that is not a coincidence — the convergence test is
`fabs(pos - _homePos) < 0.003f` turns, which **is** 1.08°. The settle exits the moment it drops under
the ceiling, so where it lands is luck. **[source]**

Encoder resolution is 360/8192 = 0.0439°, about 25× finer. If tighter homing is ever wanted, that one
constant is the knob; the costs are longer settles and the risk of never converging against static
friction.

### The accumulator has a hard ceiling at ~32 768 turns

`pos_estimate` never wraps, and everything downstream is a 32-bit float whose step size grows with
magnitude. This stopped being theoretical at 3433 turns. **[source]**

| `pos_estimate` | Float step | In degrees | Consequence |
|---|---|---|---|
| 3 433 | 0.000244 t | 0.088° | reached; settle errors quantised to this |
| 16 384 | 0.00195 t | 0.70° | inside the 0.003-turn tolerance, barely |
| **32 768** | 0.0039 t | 1.41° | **step exceeds the tolerance** |

Above ~32 768 turns the difference between two nearby positions is either exactly zero or larger than
the tolerance — nothing in between — so the settle can only pass on a bit-identical match and will
otherwise time out on a mechanically perfect machine. At ~833 turns per `fullcode.gcode` run that is
roughly **39 production runs per ODrive power cycle**. The mitigation is free: power the ODrive down
periodically, which zeroes the accumulator.

The observed `BootSettleErr=0.00` and `HomeSettleErr=0.09` at 3433 turns are *exactly zero and one
float step*. Do not read 0.00° as perfection.

### Two UI defects, both of which blocked diagnosis

**No identity check on connect.** Both USB devices are CDC-ACM and swap `/dev/ttyACM` numbers freely.
On 2026-08-17 a power cycle exchanged them — the ODrive vacated `ttyACM0` at 16:03:58, the Mega
re-enumerated first at 16:04:07 and claimed it — and Chrome's remembered port then pointed at the
ODrive. Every G-code came back `unknown command`, which is the **ODrive's ASCII protocol answering**,
not Marlin refusing. It reads exactly like the firmware losing its command set, and it cost most of a
session. **[bench]**

**The Verbose checkbox could never show telemetry.** `processLine()` let `TELEM:` lines fall through
when Verbose was ticked, then excluded them from `logRx()` unconditionally a few lines later. No
setting anywhere in the UI would print a `DEG=` value; the circular dial was the only angle readout
and it cannot be read to 2°. This forced the entire T3 measurement onto SSH. **[source]**

Both fixed in PR #78, stacked on #73.

---

## 3. The Mega's USB link is intermittently faulty

**Top hardware item.** **[bench]**

- **53 enumerations** since the laptop booted 2026-08-13 02:02:53. Currently `Bus 003 Device 054`.
  It was 44 / Device 048 when this section was first written on 2026-08-19. Some of the nine since
  then fall inside the hands-on wiring window that afternoon and may be operator-caused, but the most
  recent — **2026-08-20 14:51:47** — does not. **The fault is still live.** Re-count with the §6
  command before drawing conclusions; these numbers go stale within a day.
- Intervals are **irregular** — 10.7 min to 1293.7 min. Not a schedule, not a cron job.
- Several occurred **with nobody in the building** (02:16, 03:59, 05:15, 06:27).
- **Isolated to the Mega**, with one asterisk. The ODrive held `Bus 001 Device 010` from 2026-08-17
  16:04:13 without flapping, which is what rules out shared power and the hub. It then re-enumerated
  three times on 2026-08-19 (15:01, and twice at 15:20) — all during hands-on wiring work, so
  operator-caused rather than spontaneous, but the isolation argument now rests on that judgement
  rather than on an unbroken record. **[bench]**
- **Not autosuspend.** Both devices have `power/control=on`, and the Mega's
  `runtime_suspended_time` is 0 — it has never been suspended.

Suspects in order: the USB cable, the connector at either end, the laptop port.

A marginal link is also the most economical explanation for the GUI failures — it would produce full
disconnects sometimes (logged) and transient I/O errors other times (not logged), and Chrome holds
the port continuously while `pyserial` sessions last seconds. **[inferred]** — plausible and
unifying, but **not demonstrated**: at least one GUI failure fell in a window with no logged USB
event.

**Swap the cable and move it to a different port before anything else.** It tests both problems at
once and costs nothing.

---

## 4. The GUI problem, unsolved

Chrome connects at 250000 baud, receives Marlin's `start`, then fails with
`Read error: The device has been lost.`

Ruled out, each with evidence:

| Hypothesis | Killed by |
|---|---|
| Port contention with SSH probes | recurred with nothing else touching the port |
| Stale Chrome device-service state | survives a full Chrome restart and a fresh profile |
| PR #73's reconnect rewrite | the committed baseline UI fails identically |
| Chrome auto-updated mid-session | installed 2026-08-12, untouched since |
| Non-standard 250000 baud | `start` decodes cleanly, so the rate is set correctly |
| Hardware / cable / driver | `pyserial` works every time, same device, same baud |
| Kernel-level disconnect | no USB or tty event logged during the failures |

Armed and waiting for one reproduction: Chrome under
`systemd-run --user --unit=rmr-controller` with a **clean profile** (`/tmp/rmr-chrome-profile`),
verbose serial logging (`--vmodule=*serial*=3`) streaming to the journal, a **normal window** so
`chrome://device-log` is reachable, and `udevadm monitor` writing to `/tmp/udev.log`.

The unexamined view is `chrome://device-log` — Chrome's own record of device arrival and removal.

---

## 5. How to reach the machine

| | |
|---|---|
| Bench laptop | on-site laptop, Ubuntu 26.04, GNOME 50 on **Wayland** |
| Repo on laptop | `~/Robot-MakingRobot`, on `fix/69-boot-honest-index-search` |
| Mega | `/dev/rmr-mega` — `2341:0042` |
| ODrive | `/dev/rmr-odrive` — `1209:0d32` |

Host name, network address, account and remote-desktop details are kept off this public
repo; the owner holds them privately.

**Never address either device by `ttyACM` number.** They swap. Always `/dev/rmr-mega` and
`/dev/rmr-odrive`; the udev rules are keyed on serial number for exactly this reason (#65). In
Chrome's port picker, select by USB id.

**Sending G-code over SSH** — `stty` cannot set 250000 baud. Use pyserial:

```bash
~/.platformio/penv/bin/python -c "
import serial,time
p=serial.Serial('/dev/rmr-mega',250000,timeout=0.3); time.sleep(3); p.reset_input_buffer()
p.write(b'M115\n')
for _ in range(60):
    l=p.readline()
    if l: print(l.decode(errors='replace').rstrip())
"
```

Opening the port resets the Mega via DTR. Nothing moves on boot — `Spincoater::boot()` is deferred to
the first `M750`/`M751`/`M752` — but it destroys the in-RAM datum. **[source]**

**Relaunching the UI over SSH** needs `--ozone-platform=wayland`, or Chrome picks the X11 backend and
dies on the missing X cookie. It also needs the session bus:

```bash
export XDG_RUNTIME_DIR=/run/user/1000
export DBUS_SESSION_BUS_ADDRESS=unix:path=/run/user/1000/bus
```

A plain backgrounded launch is reaped when the SSH session ends. Use `systemd-run --user`.

---

## 6. Do this next

Ordered. Items 2 to 4 rotate the chuck; **a person must be in the room, and must be asked
explicitly.**

**1. Swap the Mega's USB cable and move it to a different port.** No motion, costs nothing, and it is
the single most likely fix for both the re-enumerations and the GUI. Then leave it and check
`journalctl -k | grep -E 'idVendor=2341|USB disconnect'` after a few hours. **Do not grep `usb 3-2`** —
moving the cable changes the bus path, so a port-specific pattern reports a clean bill of health
whether or not the fault persists.

**2. Flash PR #76 and run a spin that actually completes.**

```gcode
M751
M750 S1000 D10 A3 C3 H0
```

Expect the measure phase to run the full 10 s and emit `MeanRPM`, `StdDevRPM` and `Samples` near 100,
rather than aborting at 3 s. **This has never happened on this machine.** It also unblocks the
coast-time measurement that PR #57's thresholds are still guessing at.

**Done 2026-08-19.** Confirmed on the first attempt after flashing: the measure phase ran the full
10 s with no abort — the first complete spin cycle in this machine's history. **[bench]**

First statistics block, 2026-08-19: `Samples=99`, `MeanRPM=1009.88`, `StdDevRPM=4.47` (0.44 %),
`MinRPM=1001.59`, `MaxRPM=1018.07`, `Range=16.48` — spread symmetric about the commanded 1010, so
ripple rather than drift. Task 8 followed: 8.2 passed twice (`MEASURE_LINK_LOST` within 3 s of
pulling ODriveTX, and **no** statistics block, so the `1e9` sentinels did not leak) and 8.3 passed
(`DECEL_LINK_LOST`, last seen 58.59 RPM against a 6 RPM exit threshold). **[bench]**

**First clean end-to-end cycle in this machine's history, 2026-08-19.** `M750 S1000 D10 A3 C3 H1`
ran measure, ramp-down, settle, index home and datum normalisation without intervention, ending
`OK: INDEX_COMPLETE` then `OK: CYCLE_COMPLETE`. `Samples=100`, `MeanRPM=1010.02` — 0.02 RPM from the
commanded 1010, against 0.12 on the previous run, which settles the overshoot explanation in §7.
`StdDevRPM=4.54` and `Range=14.65` reproduce the earlier 4.47 and 16.48. **[bench]**

`DatumNormalised turns=-442 newHomePos=1281.00`, then `HomeSettleErr=0.88 deg` — a third
confirmation of PR #71, at the largest offset yet (previously -206 and -104). Task 8 is complete:
8.1, 8.2, 8.3 and 8.4 all pass, so PR #57 is validated on hardware. **[bench]**

Note the accumulator reached **1281 turns** in one afternoon, at roughly 217 turns per cycle. The
float ceiling in §2 is ~32 768. Powering the ODrive down between sessions costs nothing and resets it.

**Run sheet Task 6, 2026-08-19.** 6.2, 6.3, 6.5 and 6.6 pass — including 6.5, which floods the
command buffer before sending `M112` and is the actual claim `EMERGENCY_PARSER` makes. **PR #51 is
validated.** `M999` recovery needs only a GUI reconnect, not a USB replug — see §8.

**6.4 fails, and it uncovered a worse hazard than the one it tests.** Disconnecting USB mid-spin did
not stop the chuck; the cycle completed and homed. `M750` is a blocking handler with no host-presence
check, so that is exactly what the code specifies — 6.4 asserts a property never implemented. The
adjacent case is the dangerous one: *reconnecting* toggles DTR and resets the Mega, and since
`boot()` is deferred, Marlin's startup touches the ODrive not at all, leaving it holding its last
commanded velocity with no supervisor. Filed as **#81**, with the accumulator as **#80**. Not a
defect in #51. **[bench]** + **[source]**

Standing mitigation, stated by the owner 2026-08-19: the **master power switch is within the
operator's reach at all times** and the machine is operated attended. Note that using it also
power-cycles the ODrive, which zeroes `pos_estimate` and erases the datum — `M751` afterwards.

**3. Redo the T3 physical-mark check.** Numerically T3 passed; this is the corroboration lost to the
overnight power-down. Mark the chuck, then:

```gcode
M752
M751
M750 S1000 D10 A3 C3 H0
M752
```

`M752` first lets `boot()` run once; `M751` sets the datum — photograph the mark at that point.
**No Mega reset between the last two commands** — `boot()` re-datums to the current position and
silently voids the test. If the mark returns, merge #71 and #72.

**Done 2026-08-19. The mark returned.** `HomeSettleErr=0.22 deg` — inside the 1.08° tolerance, so
bounded by it rather than measuring the machine. #71 and #72 are cleared to merge. **[bench]**

**4. T5, the honest-failure check.** Power the ODrive down, disconnect the encoder index wire from
GPIO10, power up, reset the Mega, `M752`. It must report *no valid datum* rather than announcing one.
Reconnect the wire afterwards and confirm with one clean `M752`.

**Held by the owner, deliberately.** T5 and run sheet Task 7.4-7.7 are the same encoder-index-wire
pull, and Anatol is holding both until he is at the machine in person, for accountability — this is
the one test whose entire purpose is proving the machine fails honestly. **Do not pick it up in his
absence.** Nothing is blocked by the wait: #56 stays partly unvalidated, which matters only when the
merge reaches it. Also note that T1-T5 are defined nowhere in this repo; only T3 and T5 are ever
named, and the numbering came out of the 2026-08-17 session without being written down.

**5. Then merge, bottom-up, in the forced order,** and resume Tasks 6 to 10.

**6. The next session is the operator GUI**, not the bench. #62 now carries the agreed spec for a
standalone segment runner — marker-defined segments with session-only UI overrides, bounded
parameter declarations, a per-layer table, and pause/re-run between segments.

**#48 and #47 are hard prerequisites, not related work.** #48: the Program Runner's wait-for-ok is
defeated by auto-report `M114` oks, so it bursts lines after a blocking `M750` — and a segment runner
is built on exactly that mechanism. #47: `ERR:` lines are unmapped in both UIs, so a runner cannot
fail a segment and would walk past a failed spin into the next one. On a program that presses a
filter onto a chuck, that is the failure you least want. Both are UI-side and need no hardware.

**Done 2026-08-19, all three, as PRs #83, #84 and #85.** No hardware was touched — the work is
UI-side, and the GUI belongs to Anatol (decision 15). Each was driven under a stub DOM instead: the
shipped `<script>` is loaded and its real functions called, so the checks exercise what ships rather
than a re-implementation. **None of it has run against the machine.** Bench steps are in each PR
body.

- **#83 (#48)** stacks on #78. Every command written is recorded and each `ok` consumes exactly one
  record. Measured on identical wire traffic, a six-`ok` burst fired **6** program lines before and
  **1** after. It also carries three adjacent defects of the same family: Resume double-sent while a
  line was still outstanding, E-stop left the program running and the poll talking to a killed board,
  and `RMR_Touch`'s homing indicator cleared on whichever `ok` arrived first rather than on `G28`'s.
- **#84 (#47)** stacks on #83. `OK:` and `ERR:` are now branches on the message class, so a failure
  token can never be claimed by the success test. 13 of 17 checks fail before it and all 17 pass
  after, in both UIs.
- **#85 (#62)** is `RMR_SegmentRunner.html`, standalone, stacked on #82. Both prerequisites are built
  in natively rather than inherited, since it shares no code with either UI. 63 checks pass.
  `LayerCycle.segments.gcode` is `LayerCycle.gcode` with markers and 14 parameters added, verified
  line-by-line: at default values and one layer it sends the same 50 executable lines in the same
  order as the plain file.

**#62 §9 needed nothing.** Its four `DemoProgram.gcode` defects describe the program that became
`LayerCycle.gcode`, and PR #82 corrected all four. `DemoProgram.gcode` on `main` is the 2026-08-05
pick-and-place and contains none of them. **[source]**

---

## 7. Findings that must not be re-derived

- **The index reference is modulo one turn.** Everything about datum comparison follows from it.
- **`pos_estimate` is a continuous multi-turn accumulator** (`circular: False`). It never returns to
  zero and is not supposed to. It has a **float ceiling at ~32 768 turns** — §2.
- **`boot()` re-datums to wherever the rotor is.** So `M752` immediately after a Mega reset can never
  exercise datum normalisation; `roundf(_homePos - guard_pos)` is always 0. Set the datum first,
  accumulate turns, and do not reset in between.
- **A Mega DTR reset does not touch `pos_estimate`.** That lives in the ODrive. To preserve turn
  count, reset the Mega; to zero it, power the ODrive.
- **`M750`'s `D` is the hold duration, exclusive of ramps.**
- **`M750 S<rpm>` holds `rpm + 10`, not `rpm`.** `M750.cpp` commands a deliberate +10 RPM overshoot
  so the ramp-up threshold (98 % of target) is reachable, and never backs it off — the measure phase
  runs at the overshot speed for its whole duration. The first statistics block this machine produced
  reads `MeanRPM=1009.88` against `S1000`, which is 0.12 RPM from the *commanded* 1010 and 9.88 from
  the *requested* 1000. Do not read that 9.88 as a tracking error; the loop is tracking almost
  perfectly. It is 1 % fast at `S1000` and 0.2 % fast at `S5000`. **[bench]** + **[source]**
- **The settle tolerance is 1.08°** (`0.003f` turns). Reported settle errors are bounded by it, not
  by the machine.
- **The ODrive does not index-search on power-up** (`startup_encoder_index_search: False`).
  `index_offset_valid: True` means "we know where the index is", not "we know where we are".
- **The ODrive config exists only in NVM.** `ODRIVE_CONFIG.md` (PR #74) records it but is not a
  backup. Run `odrivetool backup-config` before touching ODrive firmware.
- **`axis0.pos_estimate`**, not `axis0.pos_vel_mapper.pos_estimate`.
- **`stty` cannot set 250000 baud.** Use pyserial.
- **`idle()` does not dispatch serial commands.** `MarlinCore.cpp:778` services steppers,
  temperature and the LCD; it never calls `queue.get_serial_commands()`. So during a blocking
  handler — `M750`, `G28`, `G4 S50` — **nothing at all is consumed from the port**. Incoming bytes
  only accumulate in the 128-byte hardware ring (`RX_BUFFER_SIZE` default, `Conditionals_adv.h:959`),
  and `MarlinSerial.cpp:170` discards the overflow **silently**: `SERIAL_STATS_DROPPED_RX` is off, so
  not even a counter moves. Two consequences, and they are the whole of #48: anything sent during a
  blocking command is answered in a **burst** when it returns, and past ~128 bytes it is not answered
  at all because it was never received. **[source]**
- **The ODrive answers a bad property path with `invalid property`**, and an unrecognised command
  with `unknown command`. Neither looks like Marlin, which says `echo:Unknown command: "M750"`
  followed by `ok`.

---

## 8. Traps

- **A serial port has exactly one holder, and Linux will not enforce it.** Two readers each get
  fragments. Disconnect the UI before any SSH session that opens a port, and vice versa.
- **The two devices swap `ttyACM` numbers on re-enumeration.** Observed mid-session.
- **`ok` from Marlin does not mean the command succeeded.** Read the terminal marker.
- **Reaching `IDLE` proves nothing** about an index search — `procedure_result` is the only
  discriminator. This is the #43 trap.
- **A cold ODrive emits garbage.** Wait 30 s and retry before concluding anything.
- **Marlin compiles only sources listed in the feature's `build_src_filter`.** A new G-code file needs
  registering in `ini/features.ini` as well as declared and dispatched, or it fails at *link* time.
- **`M115` and the boot banner report the *previous* build's timestamp after an incremental build.**
  `__DATE__` and `__TIME__` are baked into whichever translation unit contains them — `M115.cpp:64`
  and `MarlinCore.cpp:1292`. PlatformIO recompiles only what changed, so a build that touches one
  G-code file links a new image while both strings go on naming the old build. On 2026-08-19 a
  correctly flashed board reported `Aug 13 2026 19:45:48` and read exactly like a failed upload.
  **avrdude's post-write verify is the honest check** — it reads the image back off the chip and
  compares it against the hex. Only a clean rebuild refreshes the strings. **[bench]**
- **`pkill -f chrome` matches the shell running it** when that command line contains the word. Use
  `pkill -x chrome`.
- **`M999` does not restart the board after `M112` on this machine.** A **GUI disconnect/reconnect is
  enough** — it toggles DTR, which resets the Mega. A physical USB replug was *not* needed on
  2026-08-19, contrary to what this trap said before. Either way the in-RAM datum is erased; send
  `M751` again. **[bench]**
- **The bench laptop's clock jumped ~3 days during the 2026-08-17 session** when NTP corrected it. Any
  log timestamp written before the correction is offset. It is NTP-synced and correct now.
- **Never pipe a long bench run through `head`.** It closes the pipe, kills the SSH session, and can
  cut a script off mid-sequence. Redirect to a file on the laptop and fetch it afterwards. This
  happened on 2026-08-17 and cost a full T3 run.

---

## 9. Decisions not to relitigate

The eight in the original `HANDOFF.md` §4 and the four in `HANDOFF-2026-08-14.md` §9 all still stand.
Added since:

| # | Decision | Reason |
|---|---|---|
| 13 | **The UI verifies the board with `M115` on connect.** | The devices swap `ttyACM` numbers, and a wrong-port connection is indistinguishable from broken firmware. `M115` is read-only and moves nothing. PR #78. |
| 14 | **Telemetry is logged only when Verbose is on, but it *is* logged.** | 5 Hz would bury the console, but dropping it silently made `DEG` unreadable anywhere in the UI and forced measurement onto SSH. PR #78. |
| 15 | **Anatol drives the bench GUI; agents ask before opening a serial port.** | One holder per port. An unannounced SSH probe killed a working GUI session on 2026-08-17. |

---

## 10. Open questions

### For the bench

1. **Does swapping the Mega's USB cable stop the re-enumerations?** §3. Top item.
2. **What does `chrome://device-log` say during a GUI failure?** §4. The one unexamined view.
3. **Does a spin longer than 3 s complete once PR #76 is flashed? Answered 2026-08-19: yes.** The
   first `D10` spin after flashing ran its measure phase to completion. **[bench]**
4. **Time a real spin-down from `M750 S5000 ... C1`** — PR #57's thresholds are still guesses. Only if
   a brake resistor is confirmed present.
5. **Is a brake resistor fitted?** Still unanswered from the original handoff. Gates the e-stop design
   (#40). A 1 s decel from 5000 RPM happened accidentally on 2026-08-17 and produced no overvoltage
   fault, which is suggestive but was not a controlled test. **[bench]**
6. **Does a visibly-good `M752` ever report a non-zero `procedure_result`?** PR #56 hard-fails on it.
7. **Does disabling the thermistor stop the intermittent homing failures?** Roughly a dozen clean
   `M752` runs were logged on 2026-08-17 with no recurrence. Encouraging, not yet conclusive.
8. **#61 — the UV lamp stays on after a power cycle.** Safety-relevant, uninvestigated.
9. **Was the ODrive's USB isolator solving an observed problem, or added speculatively?** (#68)

### For the owner

10. **What angular accuracy does the DEA process need?** Stated as roughly ±2°. Present evidence:
    0.05° normalisation invariance, ~1° settle bounded by the tolerance constant, ~1.5° repeatability
    between index searches. Plausibly well inside it.
11. **Does the process need the chuck at a known angle after every layer, or only at defined points?**
    Decides whether `H` should default to 0.
12. **Merge policy** — all at once after the bench signs off, or incrementally.
13. **#62** — scoped, and built as #85. Two of its three open questions are now answered: a dry-run
    mode exists (Preview, which opens no port), and a segment is re-runnable only from a stopped or
    between-segments state. **Still open: should parameter sets be saveable as named recipes, one per
    elastomer, or is per-run entry enough?** Values persist in `localStorage` today, which is
    stickiness rather than recipes.
14. **#85 made two calls the agreed spec did not settle**, both flagged in its PR body rather than
    buried: a parameter is layer-scoped because it says `scope=layer`, not by inference from where it
    is used; and `;PROVIDES:` was added, because `;REQUIRES:` with nothing to satisfy it leaves every
    precondition permanently unmet.
15. **`LayerCycle.segments.gcode` is a second copy of the process.** The `{placeholder}` syntax
    settled in #62 cannot be sent by any other client, so the plain file has to stay. Collapsing them
    needs an inert annotation form instead — see #85's PR body. Decide once the runner has been
    proven at the bench.

---

## 11. Working agreements

From the original handoff, still in force: one issue → one branch → one PR; correctness over
efficiency; every firmware change builds before push; adversarial review before commit; every PR body
carries bench steps.

**PRs #70 to #78 and #83 to #85 have NOT had an adversarial multi-lens review.** Each says so in its
own body. #76 and #78 have reproduced bench symptoms behind them, #78's telemetry fix was verified
behaviourally in a browser, and #83 to #85 carry stub-DOM checks that fail against the pre-change
build — but none of that is the same thing, and the process exists because three of the four original
fix PRs had a self-inflicted regression caught by exactly that review. **PR #76 is itself a
regression in PR #57**, which is an argument for the process, not against it.

Also in force:

- **No motion commands without a person in the room.** `G28`, `G1`, `M280`, `M750`, `M752` and any
  G-code program. 5000 RPM chuck, UV lamp, solenoid, and **no mechanical E-stop** (#20).
- **Ask explicitly whether a person is at the machine.** Do not infer it from context. This was got
  wrong on 2026-08-17: two runs turned the chuck after the on-site colleague had left.
- **Say what you are about to run before running it.**
- **Find the log before changing anything.** Nearly every failure in this project has been silent or
  actively misleading. Each was settled by one line of log after an hour of guessing — and on
  2026-08-17 three separate theories died to one `journalctl` query each.

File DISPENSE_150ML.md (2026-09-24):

# Dispense retune — 150 mL catheter-tip syringe

Status: **implemented in the Process Sequencer's Syringe block on 2026-09-14** (both UIs), as a
device preset the Run Log can push into the sequencer in a few clicks. **Not yet run on the
machine.** The analysis below came from a separate discussion of drooling and dose precision with
the acrylic (CN9018 7.5 % HDDA); this file records the numbers, what they became in the UI, and
how each item maps onto this machine, whose plunger is the **C axis** (a homed linear axis, 1 mm/rev
lead screw, 1600 steps/mm, soft endstops 0–125 mm) and whose syringe height is the **B axis**.

## 1. The three defects the retune fixes

1. **Retract was in millimetres, not microsteps** — the root cause of air ingestion. The pull-back
   must be about 2 mm of the *tip bore*, which is a few hundredths of a millimetre of plunger.
2. **Dose rate was fast enough** that elastic storage in the plunger train and barrel was a few
   percent of the delivered volume.
3. **Nothing severed the viscous strand**, and no dwell let the stored pressure bleed off before
   the retract fired.

## 2. Measured hardware constants

| parameter | value | source |
|---|---|---|
| Barrel ID | 40.0 mm | calipers |
| Plunger area A | 1256.6 mm² | π/4 · ID² |
| Barrel stroke | 119.4 mm (UI default **120 mm**) | 150 mL / A |
| Tip exit ID | 3.8 mm | calipers |
| Tip entry ID | 6.5 mm | calipers |
| Tip taper length | 33 mm | calipers |
| Tip internal volume | 0.70 mL | (π·L/3)(r1² + r1·r2 + r2²) |
| **C axis steps/mm (this machine)** | **1600** | 1 mm/rev screw, 1/8 µstep (`DEFAULT_AXIS_STEPS_PER_UNIT`) |
| **Volume per microstep (this machine)** | **0.785 µL** | A / 1600 |
| mm of plunger per mL | 0.7958 | 1000 / A |

The original analysis assumed a 5 mm/rev screw at 1/32 µstep (1280 steps/mm, 0.982 µL per
microstep). Every quantity below is in millimetres of plunger travel, which does not depend on the
steps/mm; only the microstep counts change.

## 3. Derivation (summary)

Tip resistance, conical, at η = 20 Pa·s:
R = (8·η·L / 3π) · (r1² + r1·r2 + r2²) / (r1³ · r2³) = 4.84 × 10¹⁰ Pa·s/m³.

Fluidic compliance, dominated by the barrel hoop rather than the plunger rod:
C_barrel = 2π·r³·L / (E·t) = 2.00 × 10⁻¹² m³/Pa · C_rod = A²/k = 1.25 × 10⁻¹² · C_liquid = V/K = 0.075 × 10⁻¹²
→ C_total = 3.32 × 10⁻¹² m³/Pa; **τ = R·C = 0.16 s at η = 20, 0.24 s at η = 30**.

Stored volume per dose is ΔP·C with ΔP = Q·R:

| dose time | ΔP | plunger force | stored volume | % of 5 mL |
|---|---|---|---|---|
| 5 s | 0.484 bar | 60.8 N | 0.161 mL | 3.2 % |
| 15 s | 0.161 bar | 20.3 N | 0.054 mL | 1.1 % |

Retract sizing: 1 mm of the 3.8 mm bore is 11.34 µL. Target pull-back 2 mm of bore:
retract = π·1.9²·2 / 1256.6 = **0.0180 mm of plunger** (29 microsteps at 1600 steps/mm).

Strand pinch-off is viscous-dominated (Oh ≈ 100): t_v = η·D / (2σ) ≈ 1.19 s at η = 20 — too slow to
wait out, hence a mechanical sever.

Air ingestion is structural: the critical bore for buoyant counter-flow is
D_crit = √(0.84·σ / (ρ·g)) = 1.62 mm, and the 3.8 mm tip is well above it, so air climbs at roughly
4.5 mm/min. It is self-clearing only because each 5 mL dose flushes the 0.70 mL tip seven times over
— hence the idle purge guard.

## 4. What each item became on this machine

| Analysis item | Implementation (Syringe block, both UIs) | Note |
|---|---|---|
| `RetractE = 0.0180` mm | **Pullback (mL)** = 0.0227 mL × 0.7958 mm/mL = 0.0181 mm in the preset; the **max retract guard** is a sanity cap, **2 mm** since 2026-09-17 (0 = none) | 29 microsteps. The analysis's 0.05 mm (62.8 µL) "air ingestion" cap was tried and left the tip dripping between doses, so the guard was loosened and the pullback is set on the bench to whatever stops the drip |
| `DoseFeedE = 15.9` mm/min (5 mL in 15 s) | **Dispense feed** 15.9 mm/min (feeds accept decimals) — 424 steps/s, inside the planner's budget; the hint shows the dose time | `DEFAULT_MINIMUMFEEDRATE` is 0.0 and `MIN_STEPS_PER_SEGMENT` 6, so a 6366-step dose is never clamped |
| `G4 P800` after the dose, **before** the retract | **Dwell after dispense**, default **2 s** (owner's choice; ~3τ ≈ 0.8 s is the physics floor), a browser-side abortable sleep after the dose's `M400` | order matters: retracting a still-pressurised system nets a suck when it relaxes |
| `G1 E-0.0180 F1.0` | retract at its own **retract feed** (1 mm/min in the preset) | the planner never steps below 120 steps/s (`MINIMAL_STEP_RATE`) = 4.5 mm/min on C, so the retract effectively runs at ~4.5 mm/min (0.24 s) — still gentle |
| Z snap (fast 50 mm/s lift) | **removed 2026-09-17** — it was built (`G1 B-4 F3000` before the raise to B0) and did nothing for the strand on the bench; the raise to B0 at the positioning feed is the only lift now | — |
| Lateral shear `G1 X1.5` | **not available** | the syringe is fixed over the chuck: only B (height) and C (plunger) move; the strand is left to the pullback and the dwell |
| Wiper drag at a park XY | **not available** | no wiper hardware and no XY motion at the syringe |
| `PurgeBarrel` at start of run and after idle > `IdleLimit` | **Purge** button (2 mL at 60 mm/min → same dwell / retract) and **Purge before the first dose of a Run All** (opt-in); **idle limit** 300 s → a dose after longer idle *warns* (toast + journal) but never blocks | there is no waste position: the purge dispenses onto whatever is under the tip — put a waste cup there first (the button asks; the run-all option is the consent) |
| Generator-side E caps | **Max dose** (4.18 mm = 5.25 mL), **max retract** (2 mm, a sanity cap), **barrel stroke** (120 mm by default, checked against the last `M114` C position) — enforced in the UI before sending | the C axis also has firmware soft endstops 0–125 mm, but the barrel is shorter than the axis |

All of these are inputs in the Syringe block, so they travel with a Run Log preset: the built-in
**`CN9018 7.5% HDDA · 150 mL syringe`** preset sets calibration 0.7958 mm/mL (barrel ID 40),
dose 5 mL, pullback 0.0227 mL, dose feed 15.9, retract feed 1, dwell 2 s,
max dose 4.18 mm, max retract 2 mm, stroke 120 mm, purge 2 mL at 60 mm/min, idle limit 300 s, prime 0.5 mL,
spin 1000 RPM / 50 s / 3 / 3 / H1, cure 480 s with the lid closed, Stamp block disabled (hand
pressing). New device → preset → Apply → Create pushes all of it into the Process Sequencer. **These are also the
Syringe block's page defaults** (2026-09-14): a fresh page is already set up for the 150 mL syringe.

**Initial purge (prime).** A separate button pushes the plunger by a user-set increment (default 0.5 mL)
at the purge feed with the tip where it is — no dwell or retract — for priming a fresh barrel:
press until material reaches the tip, then run the full purge. Only the stroke guard applies. Every
press is journaled by the Run Log.

## 5. Open items from the analysis, answered for this machine

- **`M82` / `M83` global across E axes** — not applicable: the plunger is the C axis; the block uses
  `G91` for the relative dose / retract and `G90` after, exactly as before.
- **`DISABLE_OTHER_EXTRUDERS` must stay disabled** — not applicable (`EXTRUDERS 0`). The equivalent
  concern, the syringe-height lead screw (B, 5 mm/rev, on the self-locking boundary) de-energising
  while the plunger runs, is already covered: `DISABLE_IDLE_J` and `DISABLE_IDLE_K` are **off** in
  `Configuration_adv.h`, so B and C stay energised (only X and Y idle-off).
- **Stopper stick-slip** — 15 s gives 0.27 mm/s of stopper travel, in the stick-slip regime for a dry
  PP barrel. If the bead pulses, raise the dose feed to ~24–30 mm/min (8–10 s) and accept ~2 %
  stored volume. Do **not** silicone-lubricate the stopper.
- **E-stop drops the plunger driver enable** — `kill()` ends in `stepper.disable_all_steppers()`,
  which releases every axis including C (pin 20 ENA).

## 6. Test plan (unchanged, with this machine's numbers)

1. **Retract audit.** Every `G1 C-` the sequencer emits is the pullback set in the block, capped by the
   max-retract guard (2 mm by default; the Node test asserts `G1 C-0.0181 F1` for the preset and
   `G1 C-0.3979 F1` for a 0.5 mL drip-stopping pullback).
2. **Dry run.** One dose with an empty barrel; confirm the 15.9 mm/min move is not clipped (watch the
   dose take ~15 s).
3. **Gravimetric calibration.** n = 20 doses at 80 %, 50 % and 20 % fill on a 0.01 g balance; target
   5.25 g at ρ ≈ 1.05; accept if CV < 2 % at every fill level **and** no trend with fill level (a trend
   means residual gas in the barrel).
4. **Strand check.** 20 consecutive doses, visual; no strand on the substrate. If strands persist, tune the
   pullback and the dwell — the fast snap lift was removed (no effect on the bench) and there is no lateral
   shear on this machine.
5. **Drain test.** Park the loaded tip over a tared weigh boat for 10 min and weigh; bounds are
   0.05 mL/min (air-ingress limited) to 1.52 mL/min (tube-resistance limited). The measurement sets the
   **idle limit**; 300 s is a placeholder.

## 7. Safety notes

- The dose / retract / stroke caps live in the UI. Hand-written G-code bypasses them (the firmware
  soft endstops 0–125 mm on C still apply).
- The 150 mL barrel is roughly 30 doses of residence time in the machine: wrap it against ambient UV
  and confirm the material has equilibrated to room temperature — η is strongly temperature dependent
  and every number above assumes η ≈ 20–30 Pa·s.
- A purge dispenses onto whatever is under the tip. Put the waste cup there before pressing Purge or
  ticking purge-on-run.

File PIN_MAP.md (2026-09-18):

# Robot-Making Robot — Pin Map and Wiring Reference

**Platform:** Arduino Mega 2560 running Marlin 2.1.2.7, custom board `BOARD_RAMPS_14_RMR` (ID 1020).

**Authoritative source:** `Marlin-2.1.2.7/Marlin/src/pins/ramps/pins_RAMPS_14_RMR.h` (plus inherited assignments from stock `pins_RAMPS.h`). This document consolidates and mirrors those headers for bench/wiring use. If the two disagree, the `.h` file wins — update this document.

**Last updated:** 2026-09-01 (Syringe converted from E0 extruder → K homeable linear axis, G-code letter 'C', endstop on pin 63)

---

## Quick physical summary

- 6 stepper drivers (DM556T externals): X, Y (1 driver / 2 motors), Z, Filter Feed (I), Syringe Height (J), Syringe (K)
- 6 homing endstops: X, Y, Z, I, J, K (Syringe converted E0 extruder → homeable K axis; endstop at fully-open end, pin 63)
- 2 servos: gripper (pin 5), lid (pin 6)
- 2 opto-isolated relays: UV lamp, solenoid valve (current modules: active-HIGH; original Bestep JQC3F-03VDC-C were active-LOW; 3.3 V buck rail)
- 1 spincoater: ODrive S1 on Serial2 (115200 baud raw ASCII)

---

## Stepper drivers (all DM556T externals, 1/8 microstepping, 1600 steps/rev)

Pin columns show the Mega GPIO number in decimal. For analog pins, the `Ax` alias is shown first with the digital-equivalent number in parentheses (e.g. `A0 (54)`).

| Marlin Axis | G-code Letter | Function | Driver | PUL | DIR | ENA | Steps/mm | Travel (mm) | Notes |
|---|---|---|---|---|---|---|---|---|---|
| X | X | Gantry X | DM556T #1  | A0 (54) | A1 (55) | 38 | 57.14 | 770 | GT2-14 pulley (28 mm/rev) |
| Y | Y | Gantry Y1 | DM556T #2a | A6 (60) | A7 (61) | A2 (56) | 57.14 | 150 | GT2-14 pulley. Drives the first Y motor. |
| Y2 | — | Gantry Y2 | DM556T #2b | 36 | 34 | 30 | (follows Y) | — | Second Y motor on its **own** DM556T driver with its own PUL/DIR/ENA signal set. `Y2_DRIVER_TYPE` is defined in `Configuration.h` so Marlin pulses this pin set in lockstep with the Y pin set — step/direction signals are synchronized by the firmware, not by a splicing the Mega outputs together. Auto-squaring (`Y_DUAL_ENDSTOPS`) is possible in principle since each motor has an independent driver, but it would require adding a second Y endstop (currently only pin 14 / Y_MIN is populated). |
| Z | Z | Gantry Z | DM556T #3  | 46 | 48 | A8 (62) | 320 | 186 | 5 mm/rev lead screw. `INVERT_Z_DIR true`. |
| I | A | Filter Feed | DM556T #4  | 2 | 9 | 12 | 320 | 343 | 5 mm/rev lead screw. `AXIS4_NAME='A'`. Homes to MAX. `INVERT_I_DIR true`. |
| J | B | Syringe Height  | DM556T #5  | 21 | 22 | 31 | 320 | 295 | 5 mm/rev lead screw. `AXIS5_NAME='B'`. `INVERT_J_DIR true`. |
| K | C | Syringe | DM556T #6  | 13 | 19 | 20 | 1600 | 125 | 1 mm/rev lead screw (→ 1600 steps/mm). `AXIS6_NAME='C'`, `EXTRUDERS 0`. Homeable linear axis (was E0 extruder). `INVERT_K_DIR true`, homes to MIN. Stroke ~135 mm, travel limit capped at 125 mm. Pins unchanged (13/19/20). |

Steps/mm derivation: `(motor_steps_per_rev × microstepping) ÷ linear_travel_per_rev` = `(200 × 8) ÷ travel_per_rev`.

---
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

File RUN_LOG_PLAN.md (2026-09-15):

# Run Log — DEA per-layer manufacturing log (design + decisions + what was built)

Status: **built 2026-09-14 on branch `claude/dea-progress-tracker-e9a3c4`, unmerged.** Verified in a
browser (Chrome, Controller and Touch pages) against a fake Marlin that acknowledges every command
and prints the spin statistics; **never run against the machine** — see §9. Written against `main`
at `ec98399`. Function names are the citations; line numbers drift.

## 0. TL;DR

A per-device **Run Log** that mirrors the operator's `MLDEA Reference Sheet.xlsx`: one row per
dielectric layer and one row per electrode (P/N), filled in automatically by the Process Sequencer as
it runs — time of dispense, settled (mean) RPM, UV on / cure set and actual, time of filter application
— and editable by the operator at any time. It is a **Run Log** tab in `RMR_Controller.html` and a
**Log** tab in `RMR_Touch.html` (no new page), with a one-line progress strip inside the sequencer
toolbar. **Hold** / **Break** pause a run at a chosen safe point *between* two commands and record the
pause as a row; **Log on/off** mutes recording without stopping the machine. Everything persists in
the browser (`localStorage`) and, optionally, in a folder the operator picks (JSON + CSV + XLSX kept
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

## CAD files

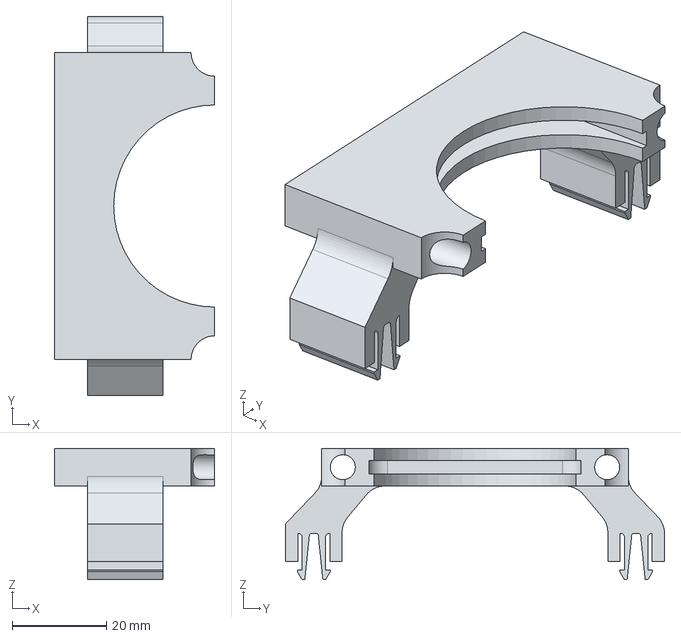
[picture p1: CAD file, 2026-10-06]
CAD/150 mL Syringe Adapter/150mLSyringeAdapter_v20260916-A-CylinderBodyClamp.step
34.0 x 80.3 x 27.8 mm

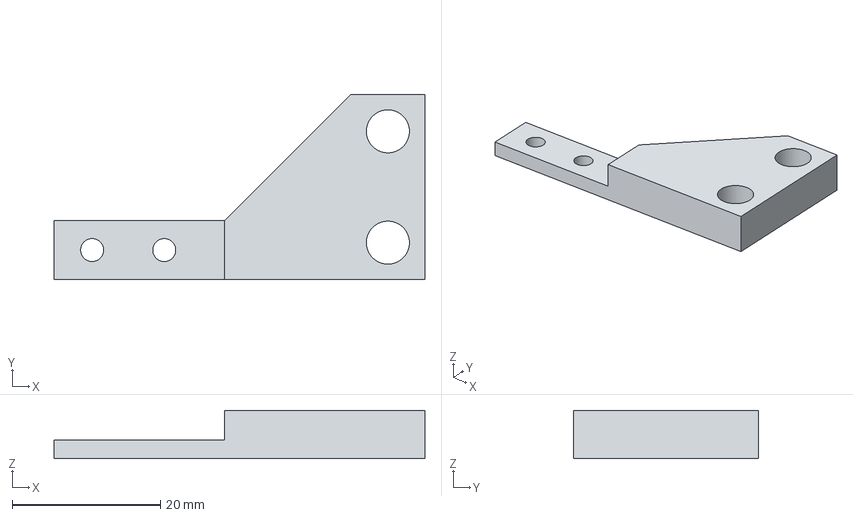
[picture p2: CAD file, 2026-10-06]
CAD/Endstops/SyringeAxisEndstop-Body.step
50.0 x 25.0 x 6.50 mm

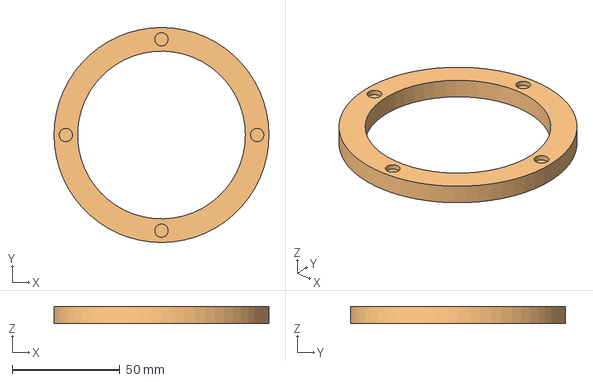
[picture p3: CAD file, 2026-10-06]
CAD/Filter Sandwich Subassembly/FilterSandwich_v20260908.FCStd
100.0 x 100.0 x 8.00 mm
01_UpperDisk
00_LowerDisk

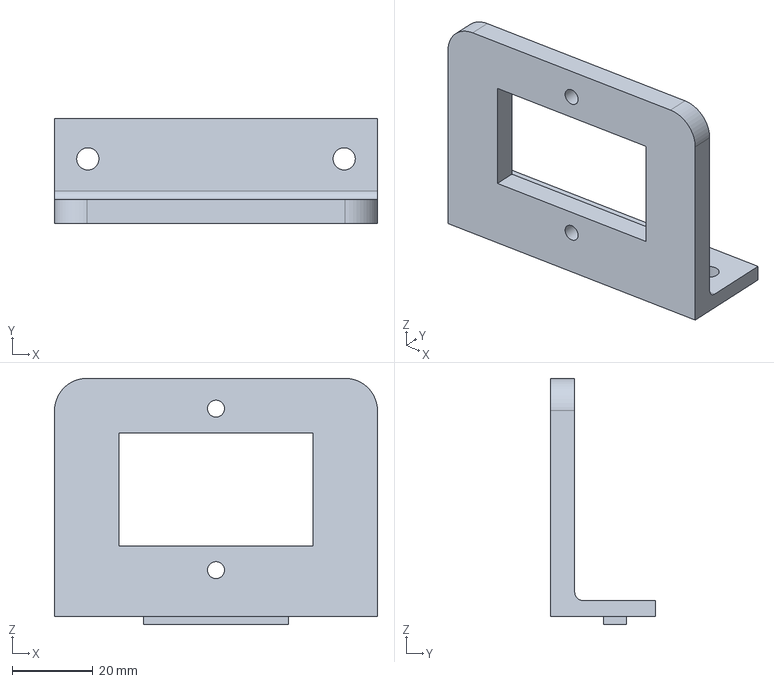
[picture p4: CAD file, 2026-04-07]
CAD/PowerSwitch2020Mount.FCStd
80.0 x 26.0 x 61.0 mm

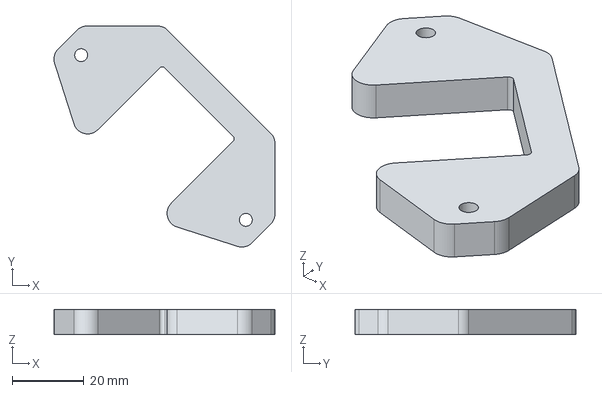
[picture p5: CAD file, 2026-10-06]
CAD/150 mL Syringe Adapter/150mLSyringeAdapter_v20260914-A-PlungerClamp.step
61.7 x 61.7 x 7.00 mm

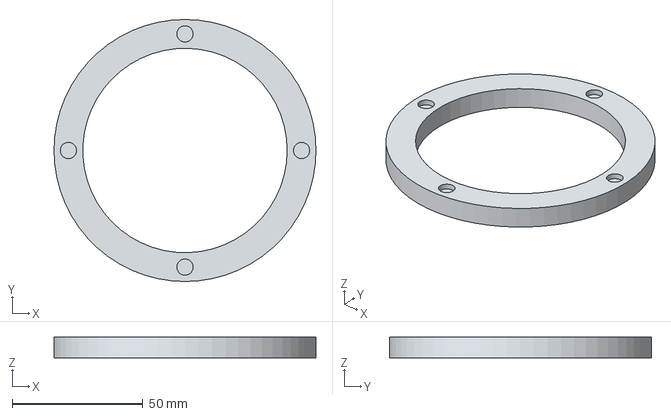
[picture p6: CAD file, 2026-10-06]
CAD/Filter Sandwich Subassembly/FilterSandwich_v20260909-A-00_LowerDisk.step
100.0 x 100.0 x 8.00 mm

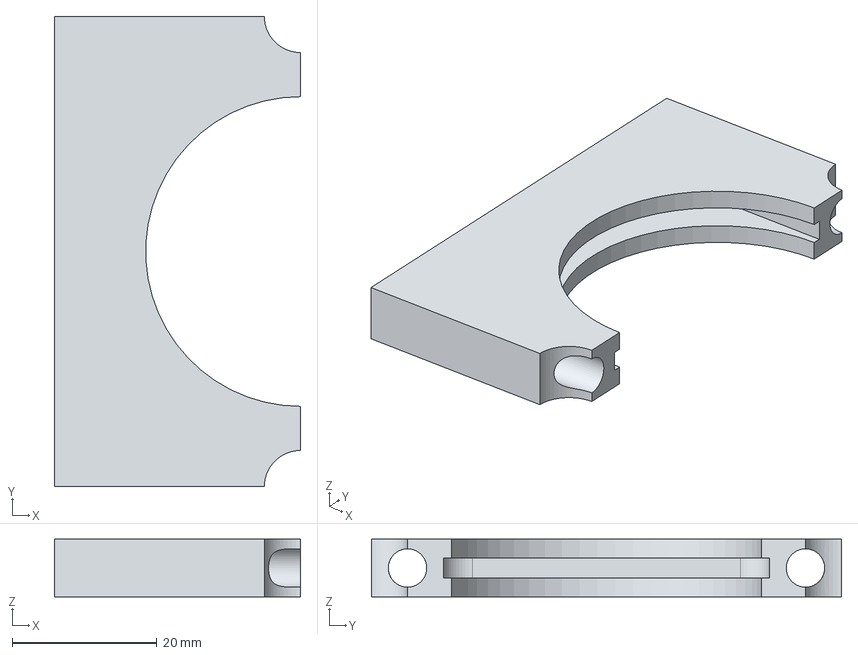
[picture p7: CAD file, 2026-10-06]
CAD/150 mL Syringe Adapter/150mLSyringeAdapter_v20260914-B-CylinderBodyClamp.step
34.0 x 65.0 x 8.00 mm

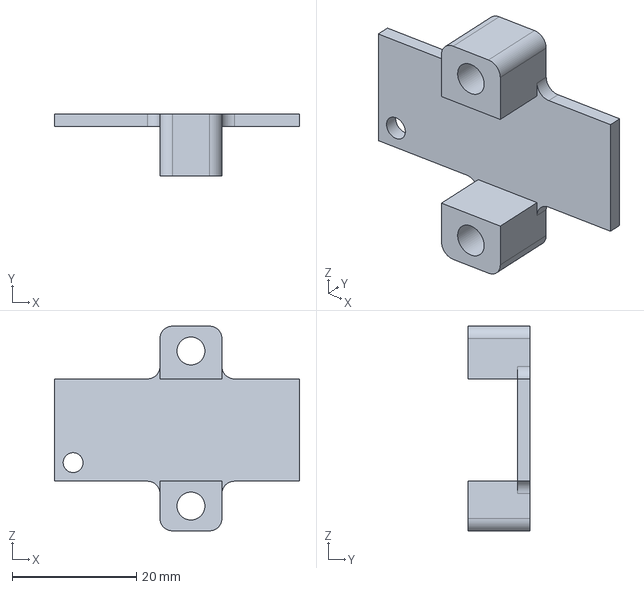
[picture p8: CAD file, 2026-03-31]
CAD/Endstops/Motor3EndStopMount.FCStd
39.5 x 10.0 x 33.0 mm

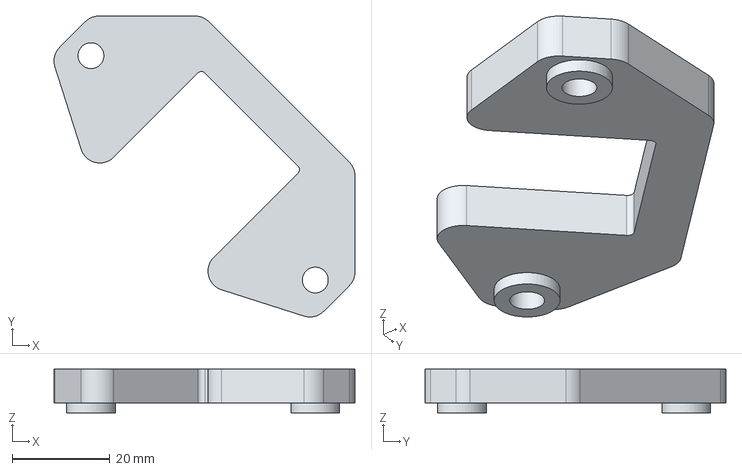
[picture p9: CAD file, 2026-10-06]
CAD/150 mL Syringe Adapter/150mLSyringeAdapter_v20260914-B-PlungerClamp.step
61.7 x 61.7 x 9.00 mm

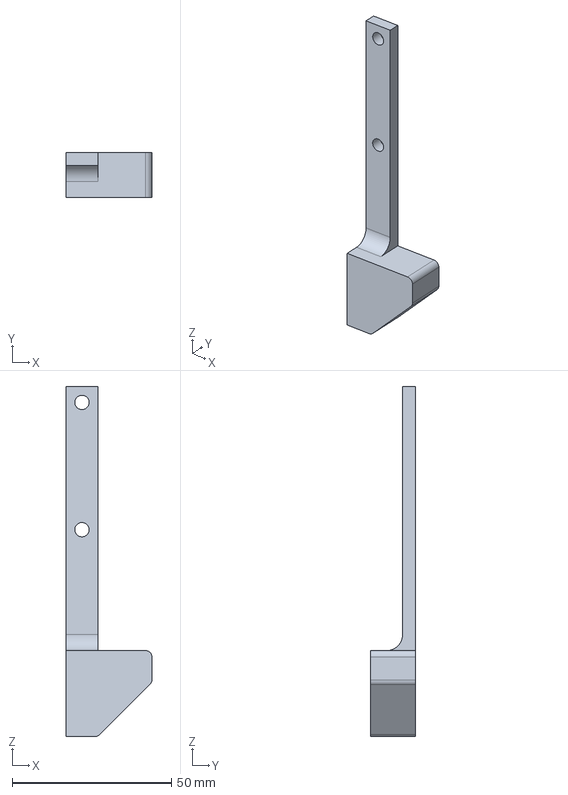
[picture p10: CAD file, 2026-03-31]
CAD/Endstops/Motor1EndStopBumper.FCStd
27.0 x 14.0 x 110.0 mm

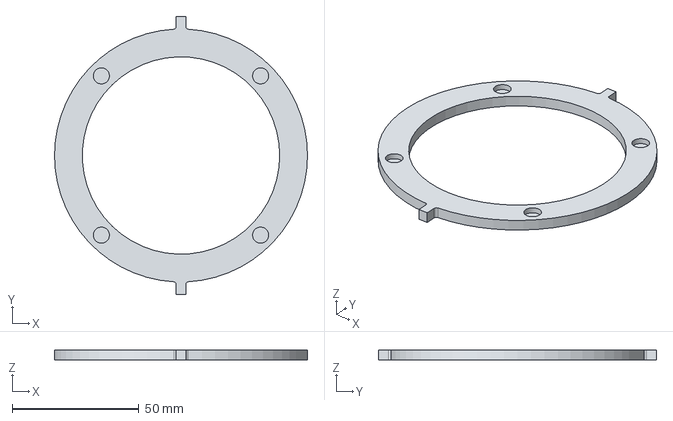
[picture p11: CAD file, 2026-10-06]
CAD/Filter Sandwich Subassembly/FilterSandwich_v20260909-B-01_UpperDisk.step
100.0 x 110.0 x 4.00 mm

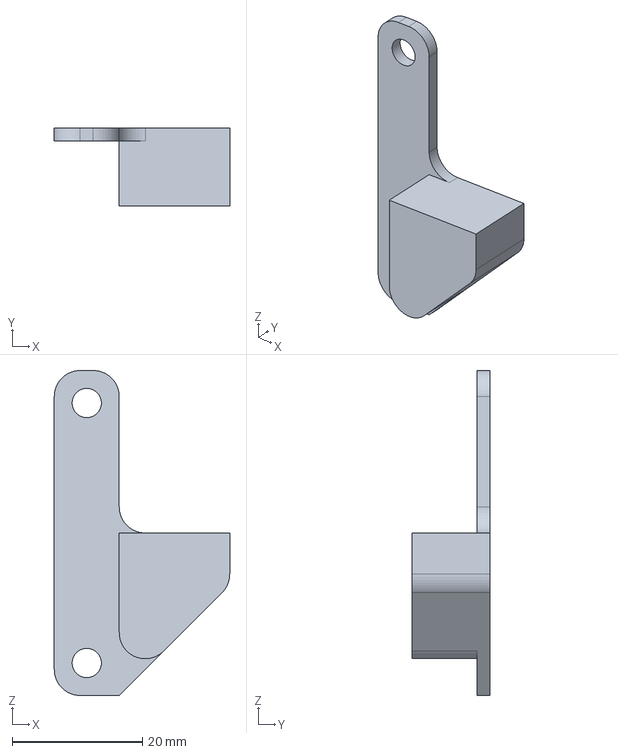
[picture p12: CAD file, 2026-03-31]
CAD/Endstops/Motor3EndStopBumper.FCStd
27.0 x 12.0 x 50.0 mm

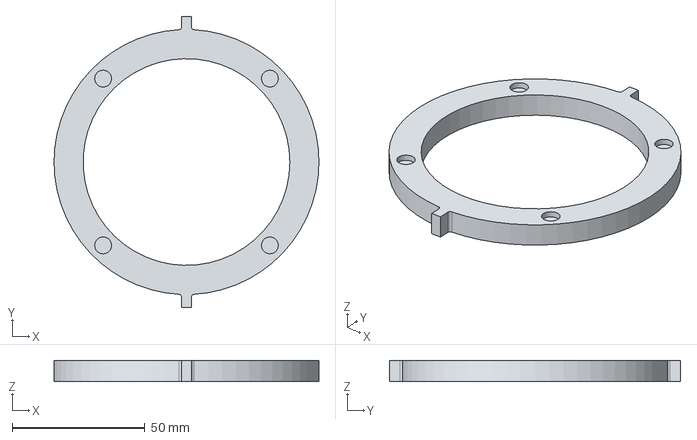
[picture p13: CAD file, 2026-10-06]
CAD/Filter Sandwich Subassembly/FilterSandwich_v20260909-B-00_LowerDisk.step
100.0 x 110.0 x 8.00 mm

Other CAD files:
CAD/Endstops/SyringeAxisEndstop.FCStd
CAD/PowerSwitch2020Mount-Body.step
CAD/Filter Sandwich Subassembly/FilterSandwich_v20260908-01_UpperDisk.step
CAD/150 mL Syringe Adapter/150mLSyringeAdapter_v20260914-A.FCStd
CAD/150 mL Syringe Adapter/150mLSyringeAdapter_v20260916-A.FCStd
CAD/150 mL Syringe Adapter/150mLSyringeAdapter_v20260914-A-CylinderBodyClamp.step
CAD/150 mL Syringe Adapter/150mLSyringeAdapter_v20260915-A-CylinderBodyClamp.step
CAD/150 mL Syringe Adapter/150mLSyringeAdapter_v20260915-A.FCStd
CAD/Endstops/Motor1EndStopBumper-Body.step
CAD/Endstops/Motor1EndStopMount.FCStd
CAD/Endstops/Motor3EndStopBumper-Body.step
CAD/Endstops/Motor3EndStopMount-Body.step
CAD/Filter Sandwich Subassembly/FilterSandwich_v20260908-00_LowerDisk.step
CAD/Filter Sandwich Subassembly/FilterSandwich_v20260909-A-01_UpperDisk.step
CAD/Filter Sandwich Subassembly/FilterSandwich_v20260909.FCStd

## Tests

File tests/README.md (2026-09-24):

# UI checks

Behavioural checks for the three browser UIs. They exist because PR bodies in
this repo make quantitative claims — "13 of 17 checks fail before this change"
— and a claim nobody can re-run is not evidence.

```bash
node tests/run.mjs        # all checks against the HTML files in the repo root
node tests/run.mjs -v     # ...with each check's own output
```

Node 18 or newer. No dependencies, no install step, nothing to build.

`harness.mjs` runs **every** inline `<script>` of a page in one vm scope, in page
order — the pre-paint theme applier, the main UI script and the shared Run Log
module at the end of the page — the way a browser does. (An earlier version took
only the first script, which after the theme work was the ten-line theme applier.)

## What they actually run

The shipped `<script>` is extracted from the HTML file and executed in a Node
`vm` context under a stub DOM, then its **real functions** are called. Nothing
is re-implemented, so a check that passes is a statement about what ships.

Two things make that work:

- `let` and `const` at the top of a `<script>` live in the script's own lexical
  scope, not on the global object, so a test cannot reach them by property
  access. The harness appends `globalThis.__ev = (s) => eval(s)` to the same
  scope; a direct `eval` sees those bindings. Tests use `ev('okLedger')` to read
  and `ev('isConnected = true')` to write.
- Elements register themselves in the stub when their `id` is assigned, so a
  test can reach an input the page built at runtime with `createElement`. The
  stub is also seeded from the markup, so defaults declared as HTML attributes
  (`checked`, `value`) are visible — the Program Runner reads several at load.
  Radio groups (a `name`, no `id`) are seeded too, with browser-style
  exclusivity, so `document.querySelector('input[name="stampSide"]:checked')`
  resolves — that is how the Stamp block reads its feeder side.

The serial port is a stub writer that appends to an array. `processLine()` is
called directly to feed a line in. That is the whole of it: no browser, no
headless Chrome, no mock framework.

## Running them on an unfixed branch

**`node tests/run.mjs` on `main` reports failures, and that is the point.** The
checks assert the fixed behaviour, so on a branch without the fix they are the
reproductions. Expected results:

| branch | result |
|---|---|
| `main` | 2 passed, 5 failed, 3 skipped — the `#48` and `#47` bugs are present |
| `fix/48-program-runner-ok-attribution` | 5 passed, 2 failed, 3 skipped — `#48` fixed, `#47` still open |
| `fix/47-ui-error-markers` | **7 passed, 0 failed**, 3 skipped |
| `feature/62-segment-runner` | 5 passed, 5 failed — based on `#82`, so the `#48`/`#47` checks run against the unfixed UIs |
| `feature/62-recipes` | 5 passed, 5 failed — same lineage, with the recipe checks included |

These numbers were produced by running the suite against each branch, not
estimated. A check whose target file is not on the branch is **skipped**; a
section covering a feature the branch predates is skipped too, which is why the
recipe checks do not fail `feature/62-segment-runner`.

## What each check covers

| file | issue | asserts |
|---|---|---|
| `ok-attribution.test.mjs` | #48 | Only a program line's own `ok` advances the Program Runner. Covers foreign traffic mid-program, pause/resume in both orderings, a write that throws, ledger overflow halting the run, and E-stop clearing the ledger. |
| `homing-indicator.test.mjs` | #48 | `RMR_Touch`'s homing indicator clears on `G28`'s own `ok`, not on whichever arrives first. |
| `runlog.test.mjs` | — | The Run Log module in either UI: the real Syringe block records the dispense at its `M400`; spin statistics are captured only between `spin.start` and `spin.done` (a `Samples=0` measure leaves the cell blank); UV on/off/aborted; hand-pressed electrodes alternate P/N and close the layer; an edited cell survives a later automatic value; Hold / Break pause between commands and a Stop during a hold rejects with `RunLogAbort`; logging off / on notes the gap; CSV and XLSX exports; localStorage persistence. |
| `runlog-sync.test.mjs` | — | The shared `RMR-RUNLOG` block is identical in both pages (line endings aside, so a CRLF checkout passes) and each page carries its glue (containers, host object, every hook, and the Touch `tabNames` order). |
| `syringe-dose.test.mjs` | — | The retuned Syringe block: exact command order (`M114` position query · lower · dose · `M400` · dwell · retract at its own feed · raise; the B snap lift is gone), the dose / retract guards refusing with nothing sent (max retract defaults to 2 mm and a 0.5 mL drip-stopping pullback passes), the stroke guard checking the fresh `M114` position rather than the readout (and refusing when the reply has no C), the purge and prime routines, `G90` still sent when a Stop or fault lands inside the relative-mode section (a Stop sends `M410` then `G90` in both UIs), barrel calibration from the bore, and the Run Log's preset → Process Sequencer apply path. |
| `stamp-block.test.mjs` | — | The Stamp block in either UI: exact command order (travel · `M400` · gripper open · feeder advance · grab · transit · press · three-step retreat · dispose); the filter feeder advances toward MIN (`G1 A-`, the axis homes to MAX) once per pick in left-/right-only mode and once per L+R pair when alternating; the lift-Z guard refusing a lift at or below the press / approach depth before anything is sent, without consuming the alternating side; the filter-feeder jog buttons (Advance = `A-`, Retract = `A+`, locked until homed, refused while a sequence runs). |
| `spin-markers.test.mjs` | #47 | `OK:`/`ERR:` are read by message class. `STATE:HOME_SETTLE` does not latch "Home datum set"; `ERR: HOME_SET_FAILED` does not read as success; `ERR: CYCLE_COMPLETE_NO_HOME` is not green; an unmapped `ERR:` still shows as an error. Marker text is taken verbatim from the firmware sources. |
| `segment-runner.test.mjs` | #62 | Load-time validation, parameter substitution and bounds, layer expansion, execution and pausing, `ERR:` failing a segment, the four guards, preview, session split/merge, the plan-rebuild guards, and recipes — save/load/delete, export/import round trip, clamping a saved value against tightened bounds, the modified flag, and the provenance block each run writes to the log. |
| `layercycle-equivalence.test.mjs` | #62 | At default parameters and one layer, `LayerCycle.segments.gcode` sends the same executable lines, in the same order, as `LayerCycle.gcode`. This is what makes the annotated copy trustworthy. |
| `syntax-check.mjs` | — | Every `<script>` block parses. Cheap, and catches the edit that broke a 1700-line file. |

## What they do not cover

Everything that needs the machine. No check here proves a servo moved, an
endstop triggered, or the ODrive answered — a stub writer accepts anything. The
serial contract they assert is Marlin's *documented* one (one `ok` per accepted
command, in order); if the firmware ever violates it, these pass and the bench
fails.

Treat a green run as "the UI logic does what we think", never as "it works on
the machine". Bench steps live in the PR bodies.

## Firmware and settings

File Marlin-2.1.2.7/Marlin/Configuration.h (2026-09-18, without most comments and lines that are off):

#pragma once
#define CONFIGURATION_H_VERSION 02010206
#define STRING_CONFIG_H_AUTHOR "(none, default config)" // Who made the changes.
#define SHOW_BOOTSCREEN
  #define MOTHERBOARD BOARD_RAMPS_14_RMR
#define SERIAL_PORT 0
#define BAUDRATE 250000
#define X_DRIVER_TYPE  A4988
#define Y_DRIVER_TYPE  A4988
#define Z_DRIVER_TYPE  A4988
#define Y2_DRIVER_TYPE A4988
#define I_DRIVER_TYPE  A4988   // Filter Feed (Motor 1) — homeable linear axis
#define J_DRIVER_TYPE  A4988   // Syringe Height (Motor 3) — homeable linear axis
#define K_DRIVER_TYPE  A4988   // Syringe (Motor 2) — homeable linear axis 'C' (was E0 extruder)
  #define AXIS4_NAME 'A' // :['A', 'B', 'C', 'U', 'V', 'W'] — Filter Feed (G1 A_ in G-code)
  #define AXIS5_NAME 'B' // :['B', 'C', 'U', 'V', 'W'] — Syringe Height (G1 B_ in G-code)
  #define AXIS6_NAME 'C' // :['C', 'U', 'V', 'W'] — Syringe (G1 C_ in G-code)
#define EXTRUDERS 0   // No extruder — Syringe is now the homeable K axis (G-code letter 'C')
#define DEFAULT_NOMINAL_FILAMENT_DIA 1.75
#define TEMP_SENSOR_0 0
#define TEMP_SENSOR_1 0
#define TEMP_SENSOR_2 0
#define TEMP_SENSOR_3 0
#define TEMP_SENSOR_4 0
#define TEMP_SENSOR_5 0
#define TEMP_SENSOR_6 0
#define TEMP_SENSOR_7 0
#define TEMP_SENSOR_BED 0
#define TEMP_SENSOR_PROBE 0
#define TEMP_SENSOR_CHAMBER 0
#define TEMP_SENSOR_COOLER 0
#define TEMP_SENSOR_BOARD 0
#define TEMP_SENSOR_REDUNDANT 0
#define DUMMY_THERMISTOR_998_VALUE  25
#define DUMMY_THERMISTOR_999_VALUE 100
#if TEMP_SENSOR_IS_MAX_TC(0)
  #define MAX31865_SENSOR_OHMS_0      100 // (Ω) Typically 100 or 1000 (PT100 or PT1000)
  #define MAX31865_CALIBRATION_OHMS_0 430 // (Ω) Typically 430 for Adafruit PT100; 4300 for Adafruit PT1000
#endif
#if TEMP_SENSOR_IS_MAX_TC(1)
  #define MAX31865_SENSOR_OHMS_1      100
  #define MAX31865_CALIBRATION_OHMS_1 430
#endif
#if TEMP_SENSOR_IS_MAX_TC(2)
  #define MAX31865_SENSOR_OHMS_2      100
  #define MAX31865_CALIBRATION_OHMS_2 430
#endif
#if HAS_E_TEMP_SENSOR
  #define TEMP_RESIDENCY_TIME         10  // (seconds) Time to wait for hotend to "settle" in M109
  #define TEMP_WINDOW                  1  // (°C) Temperature proximity for the "temperature reached" timer
  #define TEMP_HYSTERESIS              3  // (°C) Temperature proximity considered "close enough" to the target
#endif
#if TEMP_SENSOR_BED
  #define TEMP_BED_RESIDENCY_TIME     10  // (seconds) Time to wait for bed to "settle" in M190
  #define TEMP_BED_WINDOW              1  // (°C) Temperature proximity for the "temperature reached" timer
  #define TEMP_BED_HYSTERESIS          3  // (°C) Temperature proximity considered "close enough" to the target
#endif
#if TEMP_SENSOR_CHAMBER
  #define TEMP_CHAMBER_RESIDENCY_TIME 10  // (seconds) Time to wait for chamber to "settle" in M191
  #define TEMP_CHAMBER_WINDOW          1  // (°C) Temperature proximity for the "temperature reached" timer
  #define TEMP_CHAMBER_HYSTERESIS      3  // (°C) Temperature proximity considered "close enough" to the target
#endif
#if TEMP_SENSOR_REDUNDANT
  #define TEMP_SENSOR_REDUNDANT_SOURCE    E1  // The sensor that will provide the redundant reading.
  #define TEMP_SENSOR_REDUNDANT_TARGET    E0  // The sensor that we are providing a redundant reading for.
  #define TEMP_SENSOR_REDUNDANT_MAX_DIFF  10  // (°C) Temperature difference that will trigger a print abort.
#endif
#define HEATER_0_MINTEMP   5
#define HEATER_1_MINTEMP   5
#define HEATER_2_MINTEMP   5
#define HEATER_3_MINTEMP   5
#define HEATER_4_MINTEMP   5
#define HEATER_5_MINTEMP   5
#define HEATER_6_MINTEMP   5
#define HEATER_7_MINTEMP   5
#define BED_MINTEMP        5
#define CHAMBER_MINTEMP    5
#define HEATER_0_MAXTEMP 275
#define HEATER_1_MAXTEMP 275
#define HEATER_2_MAXTEMP 275
#define HEATER_3_MAXTEMP 275
#define HEATER_4_MAXTEMP 275
#define HEATER_5_MAXTEMP 275
#define HEATER_6_MAXTEMP 275
#define HEATER_7_MAXTEMP 275
#define BED_MAXTEMP      150
#define CHAMBER_MAXTEMP  60
#define HOTEND_OVERSHOOT 15   // (°C) Forbid temperatures over MAXTEMP - OVERSHOOT
#define BED_OVERSHOOT    10   // (°C) Forbid temperatures over MAXTEMP - OVERSHOOT
#define COOLER_OVERSHOOT  2   // (°C) Forbid temperatures closer than OVERSHOOT
#define PIDTEMP           // See the PID Tuning Guide at https://reprap.org/wiki/PID_Tuning
#define PID_MAX  255      // Limit hotend current while PID is active (see PID_FUNCTIONAL_RANGE below); 255=full current
#define PID_K1     0.95   // Smoothing factor within any PID loop
    #define DEFAULT_KP  22.20
    #define DEFAULT_KI   1.08
    #define DEFAULT_KD 114.00
#define MAX_BED_POWER 255 // limits duty cycle to bed; 255=full current
#define MAX_CHAMBER_POWER 255 // limits duty cycle to chamber heater; 255=full current
  #define PID_FUNCTIONAL_RANGE 10 // If the temperature difference between the target temperature and the actual temperature
#define PREVENT_COLD_EXTRUSION
#define EXTRUDE_MINTEMP 0
#define PREVENT_LENGTHY_EXTRUDE
#define EXTRUDE_MAXLENGTH 360  // longest E-axis travel: 14 inches ≈ 355.6mm
#define THERMAL_PROTECTION_HOTENDS // Enable thermal protection for all extruders
#define THERMAL_PROTECTION_BED     // Enable thermal protection for the heated bed
#define THERMAL_PROTECTION_CHAMBER // Enable thermal protection for the heated chamber
#define THERMAL_PROTECTION_COOLER  // Enable thermal protection for the laser cooling
#define USE_XMIN_PLUG
#define USE_YMIN_PLUG
#define USE_ZMIN_PLUG
#define USE_JMIN_PLUG     // Syringe Height (Motor 3) endstop on pin 17
#define USE_KMIN_PLUG     // Syringe (K) endstop at fully-open end — pin 63 (A9)
#define USE_IMAX_PLUG     // Filter Feed (Motor 1) endstop on pin 15 (far end)
#define ENDSTOPPULLUPS
#define X_MIN_ENDSTOP_INVERTING true // OpenBuilds LED switches: onboard pull-up → HIGH at rest
#define Y_MIN_ENDSTOP_INVERTING true // OpenBuilds LED switches: onboard pull-up → HIGH at rest
#define Z_MIN_ENDSTOP_INVERTING true // Set to true to invert the logic of the endstop.
#define I_MIN_ENDSTOP_INVERTING true // NO switch, internal pullup: HIGH=untriggered, LOW=triggered
#define J_MIN_ENDSTOP_INVERTING true // NO switch, internal pullup: HIGH=untriggered, LOW=triggered
#define K_MIN_ENDSTOP_INVERTING true // Syringe NO switch, internal pullup: HIGH=untriggered, LOW=triggered
#define U_MIN_ENDSTOP_INVERTING false // Set to true to invert the logic of the endstop.
#define V_MIN_ENDSTOP_INVERTING false // Set to true to invert the logic of the endstop.
#define W_MIN_ENDSTOP_INVERTING false // Set to true to invert the logic of the endstop.
#define X_MAX_ENDSTOP_INVERTING false // Set to true to invert the logic of the endstop.
#define Y_MAX_ENDSTOP_INVERTING true // Set to true to invert the logic of the endstop.
#define Z_MAX_ENDSTOP_INVERTING false // Set to true to invert the logic of the endstop.
#define I_MAX_ENDSTOP_INVERTING true // NO switch, internal pullup: HIGH=untriggered, LOW=triggered
#define J_MAX_ENDSTOP_INVERTING false // Set to true to invert the logic of the endstop.
#define K_MAX_ENDSTOP_INVERTING false // Set to true to invert the logic of the endstop.
#define U_MAX_ENDSTOP_INVERTING false // Set to true to invert the logic of the endstop.
#define V_MAX_ENDSTOP_INVERTING false // Set to true to invert the logic of the endstop.
#define W_MAX_ENDSTOP_INVERTING false // Set to true to invert the logic of the endstop.
#define Z_MIN_PROBE_ENDSTOP_INVERTING false // Set to true to invert the logic of the probe.
#define ENDSTOP_NOISE_THRESHOLD 7
#define DISTINCT_E_FACTORS
#define DEFAULT_AXIS_STEPS_PER_UNIT   { 57.1425, 57.1425, 320,  320,        320,      1600 }
#define DEFAULT_MAX_FEEDRATE          { 400, 333, 50, 33, 50, 8 }
#define DEFAULT_MAX_ACCELERATION      { 500, 200, 100, 150,  50,   500 }
#define DEFAULT_ACCELERATION          3000    // X, Y, Z and E acceleration for printing moves
#define DEFAULT_RETRACT_ACCELERATION  3000    // E acceleration for retracts
#define DEFAULT_TRAVEL_ACCELERATION   3000    // X, Y, Z acceleration for travel (non printing) moves
#define DEFAULT_EJERK    5.0  // May be used by Linear Advance
  #define JUNCTION_DEVIATION_MM 0.013 // (mm) Distance from real junction edge
  #define JD_HANDLE_SMALL_SEGMENTS    // Use curvature estimation instead of just the junction angle
#define Z_MIN_PROBE_USES_Z_MIN_ENDSTOP_PIN
#define NOZZLE_TO_PROBE_OFFSET { 10, 10, 0 }
#define PROBING_MARGIN 10
#define XY_PROBE_FEEDRATE (133*60)
#define Z_PROBE_FEEDRATE_FAST (4*60)
#define Z_PROBE_FEEDRATE_SLOW (Z_PROBE_FEEDRATE_FAST / 2)
#define Z_CLEARANCE_DEPLOY_PROBE   10 // (mm) Z Clearance for Deploy/Stow
#define Z_CLEARANCE_BETWEEN_PROBES  5 // (mm) Z Clearance between probe points
#define Z_CLEARANCE_MULTI_PROBE     5 // (mm) Z Clearance between multiple probes
#define Z_PROBE_LOW_POINT          -2 // (mm) Farthest distance below the trigger-point to go before stopping
#define Z_PROBE_OFFSET_RANGE_MIN -20
#define Z_PROBE_OFFSET_RANGE_MAX 20
#define X_ENABLE_ON 0
#define Y_ENABLE_ON 0
#define Z_ENABLE_ON 0
#define E_ENABLE_ON 0 // For all extruders
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

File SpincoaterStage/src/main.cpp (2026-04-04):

/**
 * SpincoaterStage — Arduino Nano RP2040 Connect test firmware (v2.6)
 *
 * Drives an ODrive S1 over hardware UART (Serial1) with parameterized
 * spin cycles and real-time telemetry.
 *
 * v2.6 changes:
 *   - Removed ODriveUART library entirely — all communication is raw ASCII.
 *     The library uses property paths (axis0.encoder.vel_estimate, etc.) that
 *     return "invalid property" on ODrive S1, causing serial timeouts that
 *     corrupt the UART buffer and kill telemetry during ramp-down.
 *   - measureSpeed() now uses 'f 0' for Welford sampling (same as telemetry),
 *     eliminating bus contention from dual reads on Serial1.
 *   - All ODrive interactions go through odriveReadRaw(), odriveWriteRaw(),
 *     odriveFeedback(), odriveSetVelocity(), odriveGetState(), odriveSetState(),
 *     odriveClearErrors() — thin wrappers around Serial1 ASCII commands.
 *
 * Hardware (Nano RP2040 Connect):
 *   Nano pin 0  (TX1) ──► ODrive RX  (J11 pin 4, GPIO7)
 *   Nano pin 1  (RX1) ──► ODrive TX  (J11 pin 3, GPIO6)
 *   ODrive ISOVDD/ISOGND ──► Nano 3.3 V / GND
 *
 * Serial protocol (115200 baud, newline-terminated):
 *
 *   SPIN <rpm> <dur_s> <rise_s> <sink_s> <home 0|1>
 *   START           — run with current defaults
 *   SET <param> <value>  — RPM, DUR, RISE, SINK, HOME
 *   STATUS          — report params + ODrive state
 *   STOP            — emergency velocity zero (works mid-cycle)
 *   HOME            — encoder index search (does NOT reset degree datum)
 *   SETHOME         — set current position as 0° datum + emit TELEM
 *
 * Telemetry output (every ~200 ms during active phases):
 *   TELEM: RPM=<val> POS=<val> DEG=<val>
 */

#include <Arduino.h>
#include <cmath>
#include <ODriveUART.h>

// ── ODrive serial link (raw ASCII, no library methods used) ──
// The ODriveUART global MUST exist — on RP2040 mbed, its constructor
// triggers Serial1 hardware initialization that Serial1.begin() alone
// does not complete.  We never call any odrive.xxx() methods; all
// communication goes through the raw ASCII wrappers below.
static const unsigned long ODRIVE_BAUD = 115200;
ODriveUART odrive(Serial1);  // DO NOT REMOVE — needed for Serial1 init

// ODrive axis states (from ODrive firmware — these are stable across versions)
#define AXIS_STATE_UNDEFINED                0
#define AXIS_STATE_IDLE                     1
#define AXIS_STATE_FULL_CALIBRATION_SEQUENCE 3
#define AXIS_STATE_ENCODER_INDEX_SEARCH     6
#define AXIS_STATE_CLOSED_LOOP_CONTROL      8

// ── Default spin parameters (mutable via SET command) ──
static int     cfg_rpm       = 5000;
static int     cfg_duration  = 30;      // seconds
static float   cfg_rise      = 5.0f;    // ramp-up time in seconds
static float   cfg_sink      = 1.0f;    // ramp-down time in seconds
static bool    cfg_home      = true;    // encoder index search after spin

// ── Telemetry ──
static const unsigned long TELEM_INTERVAL = 200;  // ms
static unsigned long lastTelem = 0;

// ── Runtime state ──
static bool    running       = false;
static bool    stopRequested = false;
static float   lastTelemRPM  = 0.0f;   // cached from last telemetry read
static float   homePos       = 0.0f;   // encoder pos at last home (turns)

// ── Forward declarations ──
void handleCommand(const String& cmd);
void runCycle(int rpm, int dur_s, float rise_s, float sink_s, bool home);
void measureSpeed(int dur_s);
bool doHome();
void doSetHome();
bool ensureClosedLoop();
void reportStatus();
void readEncoderPosition();
void sendTelemetry();
void sendTelemNow();
void checkStop();

// Raw ASCII ODrive communication (no library)
String odriveReadRaw(const char* property);
void   odriveWriteRaw(const char* property, float value);
bool   odriveFeedback(float &pos, float &vel);
void   odriveSetVelocity(float rps);
int    odriveGetState();
void   odriveSetState(int state);
void   odriveClearErrors();

void sendState(const char* msg);
void sendOK(const char* msg);
void sendErr(const char* msg);

// ═══════════════════════════════════════════════════════════════════════════
void setup() {
  Serial.begin(115200);
  Serial1.begin(ODRIVE_BAUD);

  while (!Serial) { delay(10); }

  Serial.println("SpincoaterStage v2.6 [Nano RP2040]");
  Serial.println("Commands: SPIN, START, SET, STATUS, STOP, HOME, SETHOME");

  // ── Wait for ODrive UART to come alive ──
  // The ODrive S1 takes several seconds to boot after power-on.
  // Poll with raw 'r vbus_voltage' (works even before encoder cal).
  //
  // Send a bare newline first to flush any partial command the ODrive
  // may have buffered from a previous session / brown-out.
  Serial1.println("");
  Serial1.flush();
  delay(50);
  while (Serial1.available()) Serial1.read();  // drain echo/error

  sendState("WAITING_ODRIVE");
  unsigned long bootStart = millis();
  bool odriveReady = false;
  while (millis() - bootStart < 15000) {  // 15s timeout (was 10s)
    String vb = odriveReadRaw("vbus_voltage");
    Serial.print("DATA: UART probe: '"); Serial.print(vb);
    Serial.print("' ("); Serial.print(millis() - bootStart); Serial.println("ms)");
    if (vb.length() > 0 && vb.toFloat() > 1.0f) {
      Serial.print("DATA: Vbus="); Serial.print(vb); Serial.println("V");
      odriveReady = true;
      break;
    }
    delay(500);
  }

  if (!odriveReady) {
    sendErr("ODrive not detected on UART (15s) — check wiring and power");
    sendOK("READY_NO_ODRIVE");
    return;  // skip index search, let user debug
  }

  // ── Auto encoder index search ──
  // The AMT102 incremental encoder loses position on power cycle.
  // The ODrive MUST run an index search before it can enter closed-loop
  // control or return valid encoder readings.
  sendState("INDEX_SEARCH_BOOT");
  Serial.println("DATA: Auto index search (required after every power cycle)");

  // Ensure IDLE first
  odriveClearErrors();
  odriveSetState(AXIS_STATE_IDLE);
  delay(200);

  odriveSetState(AXIS_STATE_ENCODER_INDEX_SEARCH);

  // Wait for search to start
  unsigned long searchStart = millis();
  bool searching = false;
  while (millis() - searchStart < 5000) {
    int st = odriveGetState();
    if (st == AXIS_STATE_ENCODER_INDEX_SEARCH) {
      searching = true;
      sendState("INDEX_SEARCH_ACTIVE");
      break;
    }
    if (millis() - searchStart > 1000 && st == AXIS_STATE_IDLE) {
      // Retry — might need error clear
      odriveClearErrors();
      odriveSetState(AXIS_STATE_ENCODER_INDEX_SEARCH);
    }
    delay(50);
  }

  if (searching) {
    // Wait for completion (returns to IDLE)
    unsigned long homeWait = millis();
    while (odriveGetState() != AXIS_STATE_IDLE) {
      if (millis() - homeWait > 30000) {
        sendErr("Index search timeout (30s) — encoder may need attention");
        break;
      }
      delay(100);
    }
  } else {
    sendErr("Could not start index search — ODrive may need full calibration");
  }

  delay(300);  // let encoder settle

  // ── Return precisely to index position (same as doHome settle) ──
  // Use trapezoidal trajectory mode so the return is slow and gentle
  // instead of a violent snap from the position PID.
  sendState("INDEX_SETTLE_BOOT");
  odriveWriteRaw("axis0.controller.config.control_mode", 3.0f);  // POSITION
  odriveWriteRaw("axis0.controller.config.input_mode", 5.0f);    // TRAP_TRAJ
  odriveWriteRaw("axis0.trap_traj.config.vel_limit", 0.25f);     // 0.25 rev/s = 15 RPM
  odriveWriteRaw("axis0.trap_traj.config.accel_limit", 0.5f);    // rev/s²
  odriveWriteRaw("axis0.trap_traj.config.decel_limit", 0.5f);    // rev/s²
  delay(10);
  odriveSetState(AXIS_STATE_CLOSED_LOOP_CONTROL);
  delay(100);

  if (odriveGetState() == AXIS_STATE_CLOSED_LOOP_CONTROL) {
    // Command move to position 0 (the index mark)
    while (Serial1.available()) Serial1.read();
    Serial1.println("t 0 0.0");
    Serial1.flush();

    unsigned long settleStart = millis();
    while (millis() - settleStart < 8000) {
      float pos, vel;
      if (odriveFeedback(pos, vel)) {
        if (fabs(pos) < 0.003f && fabs(vel) < 0.05f) {
          Serial.print("DATA: BootSettleErr=");
          Serial.print(fabs(pos) * 360.0f, 2);
          Serial.println(" deg");
          break;
        }
      }
      delay(50);
    }
  }

  odriveSetState(AXIS_STATE_IDLE);
  delay(100);
  odriveWriteRaw("axis0.controller.config.control_mode", 2.0f);  // VELOCITY
  odriveWriteRaw("axis0.controller.config.input_mode", 2.0f);    // VEL_RAMP
  delay(10);

  // Read initial position via 'f 0'
  float initPos, initVel;
  if (odriveFeedback(initPos, initVel)) {
    homePos = initPos;
    Serial.print("DATA: InitialPos="); Serial.println(homePos, 4);
  }

  sendOK("READY");
}

// ═══════════════════════════════════════════════════════════════════════════
void loop() {
  if (Serial.available()) {
    String cmd = Serial.readStringUntil('\n');
    cmd.trim();
    if (cmd.length() > 0) {
      handleCommand(cmd);
    }
  }
}

// ═══════════════════════════════════════════════════════════════════════════
//  Send a telemetry line: current RPM and position
//  Rate-limited to TELEM_INTERVAL ms.  Call from tight loops.
// ═══════════════════════════════════════════════════════════════════════════
void sendTelemetry() {
  unsigned long now = millis();
  if (now - lastTelem < TELEM_INTERVAL) return;
  lastTelem = now;

  // Read both velocity and position via raw ASCII to avoid
  // getParameterAsFloat's broken sscanf on RP2040 mbed.
  // Use the ODrive 'f' command which returns both in one shot:
  //   "f <axis>\n"  →  "<pos> <vel>\n"
  // This is a single round-trip instead of two separate reads.

  while (Serial1.available()) Serial1.read();  // drain stale

  Serial1.println("f 0");
  Serial1.flush();

  unsigned long t0 = millis();
  String response = "";
  while (millis() - t0 < 100) {
    if (Serial1.available()) {
      char c = Serial1.read();
      if (c == '\n') break;
      if (c != '\r') response += c;
    }
  }
  response.trim();

  // Parse "pos vel" response
  int spaceIdx = response.indexOf(' ');
  if (spaceIdx > 0) {
    String posStr = response.substring(0, spaceIdx);
    String velStr = response.substring(spaceIdx + 1);
    float pos = posStr.toFloat();
    float vel = velStr.toFloat();
    float rpm = vel * 60.0f;
    lastTelemRPM = rpm;  // cache for decel exit check

    // Compute absolute degrees from home position
    float relTurns = pos - homePos;
    // Normalize to [0, 360)
    float deg = fmod(relTurns * 360.0f, 360.0f);
    if (deg < 0) deg += 360.0f;

    Serial.print("TELEM: RPM=");
    Serial.print(rpm, 1);
    Serial.print(" POS=");
    Serial.print(pos, 4);
    Serial.print(" DEG=");
    Serial.println(deg, 2);
  }
}

// ═══════════════════════════════════════════════════════════════════════════
//  Force-send a telemetry line immediately (bypasses rate limit).
//  Used after homing to push the updated homePos to the dashboard.
// ═══════════════════════════════════════════════════════════════════════════
void sendTelemNow() {
  lastTelem = 0;  // reset rate-limiter
  sendTelemetry();
}

// ═══════════════════════════════════════════════════════════════════════════
//  Poll USB serial for STOP command during blocking loops.
//  Must be called frequently from any long-running loop in runCycle(),
//  measureSpeed(), and doHome().
// ═══════════════════════════════════════════════════════════════════════════
void checkStop() {
  if (stopRequested) return;  // already flagged
  if (!Serial.available()) return;

  String cmd = Serial.readStringUntil('\n');
  cmd.trim();
  if (cmd == "STOP") {
    stopRequested = true;
    odriveSetVelocity(0);
    sendState("EMERGENCY STOP");
  }
  // Ignore all other commands mid-cycle — they'll get ERR after cycle ends
}

// ═══════════════════════════════════════════════════════════════════════════
//  Command parser
// ═══════════════════════════════════════════════════════════════════════════
void handleCommand(const String& cmd) {

  if (cmd == "STOP") {
    stopRequested = true;
    odriveSetVelocity(0);
    sendState("EMERGENCY STOP");
    return;
  }

  if (running && cmd != "STOP") {
    sendErr("Cycle in progress. Send STOP to abort.");
    return;
  }

  // ── SPIN <rpm> <dur> <rise_s> <sink_s> <home> ──
  if (cmd.startsWith("SPIN ")) {
    String rest = cmd.substring(5);
    rest.trim();

    String tokens[5];
    int tIdx = 0;
    while (rest.length() > 0 && tIdx < 5) {
      int sp = rest.indexOf(' ');
      if (sp < 0) { tokens[tIdx++] = rest; rest = ""; }
      else { tokens[tIdx++] = rest.substring(0, sp); rest = rest.substring(sp + 1); rest.trim(); }
    }

    if (tIdx == 5) {
      int   rpm    = tokens[0].toInt();
      int   dur    = tokens[1].toInt();
      float rise_s = tokens[2].toFloat();
      float sink_s = tokens[3].toFloat();
      int   home   = tokens[4].toInt();
      if (rpm > 0 && dur > 0 && rise_s > 0 && sink_s > 0) {
        runCycle(rpm, dur, rise_s, sink_s, home != 0);
      } else {
        sendErr("All values must be > 0. Usage: SPIN <rpm> <dur_s> <rise_s> <sink_s> <home 0|1>");
      }
    } else {
      sendErr("Need 5 args. Usage: SPIN <rpm> <dur_s> <rise_s> <sink_s> <home 0|1>");
    }
    return;
  }

  if (cmd == "START") {
    runCycle(cfg_rpm, cfg_duration, cfg_rise, cfg_sink, cfg_home);
    return;
  }

  // ── SET <param> <value> ──
  if (cmd.startsWith("SET ")) {
    String rest = cmd.substring(4);
    rest.trim();
    int spaceIdx = rest.indexOf(' ');
    if (spaceIdx < 0) {
      sendErr("Usage: SET <RPM|DUR|RISE|SINK|HOME> <value>");
      return;
    }
    String param = rest.substring(0, spaceIdx);
    String valStr = rest.substring(spaceIdx + 1);
    param.toUpperCase();

    if (param == "RPM") {
      int v = valStr.toInt();
      if (v > 0) { cfg_rpm = v; sendOK("RPM set"); }
      else sendErr("RPM must be > 0");
    }
    else if (param == "DUR") {
      int v = valStr.toInt();
      if (v > 0) { cfg_duration = v; sendOK("DUR set"); }
      else sendErr("DUR must be > 0");
    }
    else if (param == "RISE") {
      float v = valStr.toFloat();
      if (v > 0) { cfg_rise = v; sendOK("RISE set"); }
      else sendErr("RISE must be > 0");
    }
    else if (param == "SINK") {
      float v = valStr.toFloat();
      if (v > 0) { cfg_sink = v; sendOK("SINK set"); }
      else sendErr("SINK must be > 0");
    }
    else if (param == "HOME") {
      cfg_home = (valStr.toInt() != 0);
      sendOK(cfg_home ? "HOME enabled" : "HOME disabled");
    }
    else {
      sendErr("Unknown param. Use: RPM, DUR, RISE, SINK, HOME");
    }
    return;
  }

  if (cmd == "STATUS") {
    reportStatus();
    return;
  }

  if (cmd == "HOME") {
    doHome();
    return;
  }

  if (cmd == "SETHOME") {
    doSetHome();
    return;
  }

  // ── DIAG — raw UART diagnostic ──
  if (cmd == "DIAG") {
    Serial.println("DATA: === UART DIAGNOSTIC ===");
    Serial.print("DATA: Serial1 baud="); Serial.println(ODRIVE_BAUD);

    // Drain any stale data
    int stale = 0;
    while (Serial1.available()) { Serial1.read(); stale++; }
    Serial.print("DATA: Stale bytes drained="); Serial.println(stale);

    // Send a simple command and dump raw response
    const char* testCmd = "r vbus_voltage";
    Serial.print("DATA: Sending: '"); Serial.print(testCmd); Serial.println("'");
    Serial1.print("r ");
    Serial1.println("vbus_voltage");
    Serial1.flush();

    // Wait up to 2 seconds, print every byte that comes back
    unsigned long t0 = millis();
    int byteCount = 0;
    Serial.print("DATA: Response bytes: ");
    while (millis() - t0 < 2000) {
      if (Serial1.available()) {
        int b = Serial1.read();
        byteCount++;
        // Print printable chars normally, others as hex
        if (b >= 32 && b < 127) {
          Serial.print((char)b);
        } else if (b == '\n') {
          Serial.print("\\n");
        } else if (b == '\r') {
          Serial.print("\\r");
        } else {
          Serial.print("[0x");
          if (b < 16) Serial.print("0");
          Serial.print(b, HEX);
          Serial.print("]");
        }
        // Stop after newline (complete response)
        if (b == '\n') break;
      }
    }
    Serial.println();
    Serial.print("DATA: Total bytes received="); Serial.println(byteCount);
    Serial.print("DATA: Elapsed ms="); Serial.println(millis() - t0);

    if (byteCount == 0) {
      Serial.println("DATA: >>> NO RESPONSE — check: wiring, ODrive power, UART GPIO config, baud rate");
    }

    Serial.println("DATA: === END DIAGNOSTIC ===");
    return;
  }

  sendErr("Unknown command. Try: SPIN, START, SET, STATUS, STOP, HOME, SETHOME, DIAG");
}

// ═══════════════════════════════════════════════════════════════════════════
//  Read an ODrive property via raw ASCII protocol
// ═══════════════════════════════════════════════════════════════════════════
String odriveReadRaw(const char* property) {
  while (Serial1.available()) Serial1.read();

  Serial1.print("r ");
  Serial1.println(property);
  Serial1.flush();

  unsigned long t0 = millis();
  String response = "";
  while (millis() - t0 < 500) {
    if (Serial1.available()) {
      char c = Serial1.read();
      if (c == '\n') break;
      if (c != '\r') response += c;
    }
  }
  response.trim();
  return response;
}

// ═══════════════════════════════════════════════════════════════════════════
//  Read and report encoder position (does NOT change homePos)
// ═══════════════════════════════════════════════════════════════════════════
void readEncoderPosition() {
  // Use 'f 0' instead of 'r axis0.encoder.pos_estimate' — the latter
  // returns "invalid property" on ODrive S1.
  while (Serial1.available()) Serial1.read();
  Serial1.println("f 0");
  Serial1.flush();

  unsigned long t0 = millis();
  String resp = "";
  while (millis() - t0 < 300) {
    if (Serial1.available()) {
      char c = Serial1.read();
      if (c == '\n') break;
      if (c != '\r') resp += c;
    }
  }
  resp.trim();

  int sp = resp.indexOf(' ');
  if (sp > 0) {
    float pos = resp.substring(0, sp).toFloat();

    Serial.print("DATA: EncoderPos=");
    Serial.println(pos, 4);

    float deg = fmod((pos - homePos) * 360.0f, 360.0f);
    if (deg < 0) deg += 360.0f;
    Serial.print("DATA: DegFromHome=");
    Serial.println(deg, 2);
  } else {
    Serial.println("DATA: EncoderPos=read_error");
  }

  Serial.print("DATA: HomeRef=");
  Serial.println(homePos, 6);
}

// ═══════════════════════════════════════════════════════════════════════════
//  SETHOME — set current encoder position as the 0° datum.
//  This is the user-facing "Set Home" action.
// ═══════════════════════════════════════════════════════════════════════════
void doSetHome() {
  // Try up to 5 times to read ODrive position (handles slow boot)
  String resp = "";
  for (int attempt = 0; attempt < 5; attempt++) {
    while (Serial1.available()) Serial1.read();
    Serial1.println("f 0");
    Serial1.flush();

    unsigned long t0 = millis();
    resp = "";
    while (millis() - t0 < 300) {
      if (Serial1.available()) {
        char c = Serial1.read();
        if (c == '\n') break;
        if (c != '\r') resp += c;
      }
    }
    resp.trim();
    if (resp.indexOf(' ') > 0) break;
    delay(200);
  }

  int sp = resp.indexOf(' ');
  if (sp > 0) {
    float pos = resp.substring(0, sp).toFloat();
    float vel = resp.substring(sp + 1).toFloat();
    homePos = pos;

    Serial.print("DATA: HomePos=");
    Serial.println(pos, 6);

    // Emit TELEM with DEG=0.00
    Serial.print("TELEM: RPM=");
    Serial.print(vel * 60.0f, 1);
    Serial.print(" POS=");
    Serial.print(pos, 4);
    Serial.println(" DEG=0.00");
    lastTelemRPM = vel * 60.0f;
  } else {
    sendErr("Could not read ODrive position");
    return;
  }

  sendOK("HOME_SET");
}

// ═══════════════════════════════════════════════════════════════════════════
//  Report current defaults + ODrive state
// ═══════════════════════════════════════════════════════════════════════════
void reportStatus() {
  Serial.print("DATA: RPM=");      Serial.print(cfg_rpm);
  Serial.print(" DUR=");           Serial.print(cfg_duration);
  Serial.print(" RISE=");          Serial.print(cfg_rise, 1);
  Serial.print(" SINK=");          Serial.print(cfg_sink, 1);
  Serial.print(" HOME=");          Serial.println(cfg_home ? 1 : 0);

  Serial.print("DATA: ODrive state=");
  Serial.println(odriveGetState());

  String vbus = odriveReadRaw("vbus_voltage");
  Serial.print("DATA: Vbus=");
  Serial.print(vbus);
  Serial.println("V");

  float pos, vel;
  if (odriveFeedback(pos, vel)) {
    Serial.print("DATA: Velocity=");
    Serial.print(vel * 60.0f, 1);
    Serial.println(" RPM");
  } else {
    Serial.println("DATA: Velocity=read_error");
  }

  readEncoderPosition();
}
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

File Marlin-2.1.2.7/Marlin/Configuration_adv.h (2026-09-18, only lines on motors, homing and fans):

#define E0_AUTO_FAN_PIN -1
#define E1_AUTO_FAN_PIN -1
#define E2_AUTO_FAN_PIN -1
#define E3_AUTO_FAN_PIN -1
#define E4_AUTO_FAN_PIN -1
#define E5_AUTO_FAN_PIN -1
#define E6_AUTO_FAN_PIN -1
#define E7_AUTO_FAN_PIN -1
#define CHAMBER_AUTO_FAN_PIN -1
#define COOLER_AUTO_FAN_PIN -1
#define HOMING_BUMP_MM      { 5, 5, 10, 2, 2, 2 }   // (linear=mm) Backoff after first bump (X,Y,Z,I,J,K)
#define HOMING_BUMP_DIVISOR { 2, 2, 4,  4, 4, 4 }   // Re-Bump Speed Divisor (X,Y,Z,I,J,K)
#define HOME_Y_BEFORE_X                     // If G28 contains XY home Y before X
#define HOME_Z_FIRST                        // Home Z first — Z must clear before XY move to prevent tool crash
#define MICROSTEP_MODES { 16, 16, 16, 16, 16, 16 } // [1,2,4,8,16]
  #define SPINCOATER_DEFAULT_HOME       true    // encoder index search after spin

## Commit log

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2026-03-31 Add Motor1 endstop CAD; update Motor3 & configs
    Add FreeCAD and STEP files for Motor1 endstop bumper and mount (Motor1EndStopBumper.FCStd/.step, Motor1EndStopMount.FCStd). Update Motor3 endstop STEP (timestamp and minor coordinate/direction precision fixes). Also update project configuration and firmware files (Configurations.txt, Marlin Configuration.h/Configuration_adv.h, G28.cpp, pins_RAMPS_14_RMR.h) and related docs (RMR_Controller.html, claude.md) to integrate the new endstop hardware and adjust settings/pin mappings.
    [Configuration.h, Configuration_adv.h, Configurations.txt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]
2026-04-01 RMR: axis/endstop, servo, and UI firmware tweaks
    Apply custom RMR changes to Marlin sources, pinmap and web UI to match hardware: move Filter Feed endstop to MAX (pin 15) and update I axis home direction/inversion; update travel limit for Z to 250 mm; retune max feedrates and accelerations for X/Y/Z/I/J/E; increase servo delay to 2000 ms and enable DEACTIVATE_SERVOS_AFTER_MOVE to prevent jitter. Add gripper-close (servo0 → 90°) before X homing in G28, relax firmware M280 clamp (soft limits enforced in the HTML UI), and comment out the SanityCheck that blocked DEACTIVATE_SERVOS_AFTER_MOVE. Update RAMPS pin mapping (I_MAX_PIN), documentation (README.md, claude.md) to reflect axis renaming (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
    [Configuration.h]
2026-04-01 Add Program Runner, demo G-code, adjust homing
    Add a Program Runner UI and JS to RMR_Controller.html: buttons (Run/Pause/Stop), file load, textarea with line highlighting, sequencing logic (progRun/progPause/progStop/progSendNext), and handling of 'ok' responses for stepwise execution. Improve serial processing to detect 'ok' for the runner and avoid filtering it out; prevent keyboard shortcuts when focus is in inputs or textarea. Add DemoProgram.gcode and DemoProgram.txt as example pick-and-place programs for the rig. Update Marlin Configuration.h to increase homing feedrates for the rotational axes (I/A and J/B) from 4*60 to 25*60 to speed their homing.
    [Configuration.h]
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2026-04-03 spincoater v2.6: remove ODriveUART lib, fix ramp-down telemetry, add index settle
    Replace ODriveUART library with raw ASCII commands — the library uses
    property paths (axis0.encoder.vel_estimate, etc.) that return "invalid
    property" on ODrive S1, causing serial timeouts that killed telemetry
    during ramp-down and prevented post-cycle homing from ever running.
    All ODrive communication now goes through thin wrappers around Serial1:
    odriveFeedback() for 'f 0', odriveSetVelocity() for 'v 0', odriveGetState/
    odriveSetState for axis0.current_state/requested_state, odriveClearErrors
    for 'sc'. measureSpeed() Welford sampling unified with telemetry into a
    single 'f 0' read per sample, eliminating b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
    [main.cpp]
2026-04-03 spincoater v2.6: raw ASCII ODrive comms, index settle, rise/sink params, ramp safety
    Replace all ODriveUART library method calls with raw ASCII wrappers —
    the library uses property paths (axis0.encoder.vel_estimate, etc.) that
    return "invalid property" on ODrive S1, causing serial timeouts that
    killed telemetry during ramp-down and prevented post-cycle homing.
    The library global object is retained solely for its Serial1 HW init
    side-effect on RP2040 mbed.
    New raw ASCII layer: odriveFeedback() for 'f 0', odriveSetVelocity()
    for 'v 0', odriveGetState/SetState for axis0.current_state/
    requested_state, odriveClearErrors for 'sc'. measureSpeed() Welford
    sampling unified with telemetry into a s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
    [main.cpp]
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2026-04-07 docs: update README and claude.md for completed spincoater integration
    Reflects fully tested ODrive S1 integration over Mega Serial2.
    Updates repo structure, pin maps (J endstop→pin 23, Z→pin 40),
    G-code reference (M750-M753), web controller features, and gotchas
    (AVR \r\n line-ending fix). Marks integration test items as complete
    in claude.md TODO list.
2026-04-08 Add UV lamp + solenoid valve relays via M42 (D4, D42) + fix AVR M42 timer hijack
    Wire two Bestep JQC3F-03VDC-C opto-isolated relay modules into the
    Mega/Marlin firmware for UV cure lamp and dispense solenoid control,
    triggered from G-code via M42 DIRECT_PIN_CONTROL. Both modules are
    active-low and share a dedicated 3.3V buck converter rail.
    Pin assignments:
    D4 = UV lamp (RAMPS SERVO3 slot, OC0B/Timer0)
    D42 = Solenoid (AUX2_08 header, PL7, pure GPIO)
    G-code convention (active-low):
    M42 P4 S0 = UV ON M42 P4 S1 = UV OFF
    M42 P42 S0 = valve OPEN M42 P42 S1 = valve CLOSED
    Firmware changes:
    - Configuration_adv.h: enable DIRECT_PIN_CONTROL with pin assignment
    comments docum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
    [Configuration_adv.h]
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2026-04-09 docs: correct dual-Y description (2 drivers, not 1)
    The Y1 and Y2 motors are each on their own DM556T driver with
    independent PUL/DIR/ENA signal sets from the Mega. Earlier docs
    incorrectly stated that both motors were spliced to a single
    driver and that the Y2 pin set was redundant. In reality:
    - Pin set Y (A6/A7/A2) drives the first Y motor's DM556T
    - Pin set Y2 (36/34/30) drives the second Y motor's DM556T
    - Y2_DRIVER_TYPE in Configuration.h makes Marlin pulse both pin
    sets in lockstep, so synchronization happens in firmware (not
    by externally shorting the Mega outputs together)
    - Because each motor has its own driver, Y_DUAL_ENDSTOPS auto-
    squaring is possible in principle, but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
2026-04-10 Enable lid servo on pin 6 + fix phantom Z movement on XY moves
    - Uncomment SERVO1_PIN (GPIO 6) in pins_RAMPS_14_RMR.h for lid servo
    - Add full lid servo controls to HTML dashboard (0°/90°/180° presets, override textbox)
    - Disable DISABLE_IDLE_Z in Configuration_adv.h — lead-screw Z is not backdrivable,
    and the DM556T re-enable transition was causing phantom Z steps on XY moves
    - Update PIN_MAP.md, README.md, claude.md to reflect lid servo is active
    [Configuration_adv.h]
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2026-04-17 Fix solenoid pin default, S-value bug, and add UV lamp toggle to both HTML controllers
    - Fix solPin default from 4 (UV pin) to 42 (actual solenoid pin) in both
    RMR_Controller.html and RMR_Touch.html
    - Fix toggleSolenoid() in RMR_Controller.html: S255/S0 -> S0/S1 to match
    Bestep active-low relay convention (S0=energize, S1=de-energize) and
    prevent analogWrite() Timer0 hijack via M42.cpp's pin_status<=1 guard
    - Add UV lamp toggle button (pin 4) with configurable pin input to both
    HTML controllers (toggleUV function, uvOn state, FAB button in Touch UI)
2026-04-17 Ungate M280 T<ms> slow-move parameter and add lid servo speed setting
    - Remove POLARGRAPH gate from M280.cpp so any servo move can use T<ms>
    for linear angle interpolation (e.g. M280 P1 S30 T1500 for 1.5s lid open)
    - Fix interpolation loop: use write() instead of move() to avoid
    attach+safe_delay(2000ms)+detach per step with DEACTIVATE_SERVOS_AFTER_MOVE
    - Add explicit attach(0) before ramp loop; guard T=0 divide-by-zero
    - Add "Lid Servo Speed" setting (default 1500ms) to Advanced Settings in
    RMR_Controller.html and Config tab in RMR_Touch.html
    - Lid buttons auto-append T<ms>; gripper stays snappy (no T parameter)
    - Setting persisted in localStorage as rmr.lidMoveMs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
2026-04-17 Touch UI: consolidate homing, move Connect to header ribbon
    - Replace per-axis HOME buttons in jog tab with single Home All button
    - Move individual axis homing (XY, Z, A, B) to Config tab Homing section
    - Move Connect/Disconnect button to always-visible header ribbon
    - Baud rate, M999, and Haptics remain in the expandable drawer
2026-04-17 Fix relay S-value polarity and update solenoid labels
    - Flip S-value logic for UV and solenoid toggles in both HTML controllers
    (S1=energize, S0=de-energize to match actual relay module wiring)
    - Change solenoid button labels from ON/OFF to Open/Shut
2026-04-17 Fix relay S-value polarity, eliminate post-ramp servo delay
    - Revert relay S-values to S0=energize/S1=de-energize (active-low Bestep
    convention) — prior flip caused first-press no-click + inverted labels
    - M280 T-ramp: skip move() after interpolation to avoid extra 2s
    SERVO_DELAY block; do brief 250ms settle + detach instead
    - Solenoid labels: OPEN/SHUT in both HTML controllers
2026-04-17 Fix relay polarity for active-HIGH modules, set servo default to 800ms
    - Relay S-values: S1=energize, S0=de-energize (active-HIGH modules)
    - Servo move time default: 1500ms -> 800ms in both HTML controllers
2026-04-17 Replace relay toggles with explicit ON/OFF button pairs
    - Remove stateful toggle logic (solenoidOn/uvOn variables)
    - Each relay now has two buttons sending hardcoded M42 S values:
    OPEN/SHUT for solenoid, ON/OFF for UV
    - Last-pressed button highlights via sol-on CSS class
    - Eliminates polarity guessing and state-sync issues
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2026-04-17 Touch UI visual overhaul: compact jog layout, inline controls
    - Reduce jog column max height from 520px to 380px for proportional buttons
    - Remove fixed FAB bar from bottom of screen
    - Move Grip/Lid/Sol/UV controls inline on jog tab as 2-row grid panel
    (servos row + relays row, 4 columns each)
    - Shrink step-size buttons (52px -> 44px min-height)
    - Fix servo sheet modal bottom offset (56px -> 0, no FAB bar to clear)
    - Remove padding-bottom: 64px from tab content (no FAB bar)
    - Update relay highlight to use .on class (touch-btn green style)
2026-04-17 Touch UI: Tol Bright colors, aux labels, arrow fixes, step units
    - Apply Paul Tol Bright palette to all remaining hardcoded colors
    (run/stop buttons, M999 button, SVG dial labels)
    - Label aux axes: A=Filter, E=Syringe, B=Syr.Ht
    - Change aux arrows: A/B use up/down, E uses up(dispense)/down(retract)
    with swapped button positions to match physical direction
    - Remove Z=0 and E=0 buttons (unused)
    - Add 12px gap between Z buttons to reduce chunky feel
    - Add "mm" units to step-size buttons (0.1 mm, 1 mm, etc.)
2026-04-17 Touch UI visual overhaul: Paul Tol Bright theme, layout improvements
    Design language:
    - Buttons/interactables: #4477AA blue, white text, no borders
    - Panel backgrounds: #000000 black with #BBBBBB grey 2px borders
    - Main background: #000000 black
    - Header/tab bar: #4477AA blue with #AA3377 purple accents
    - Labels: #66CCEE cyan, values: #fff white
    - Special buttons: green (#228833) start/run, yellow (#CCBB44)
    pause/set home, red (#EE6677) stop/e-stop
    - Homing overlay: Tol Bright yellow (#CCBB44)
    Layout changes:
    - Compact jog columns (max 400px height)
    - XY overflow fix, Z buttons with gap, Z=0/E=0 removed
    - Aux axes: grid layout with fixed 60px label column for alignment,
    labeled A (Filte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
2026-08-12 Do not report NoMachine as installed when the download was not a .deb
    wget returns 0 when a server hands back an HTML error page, so a moved
    NoMachine URL produced a garbage /tmp/nomachine.deb, apt failed with
    "Invalid archive signature", and the script then printed the success line
    anyway because it was not gated on the install result.
    Observed on the real bench laptop. Now validates with dpkg-deb --info
    before installing, and each outcome reports honestly.
2026-08-12 Join the WireGuard mesh instead of running an autossh reverse tunnel
    The lab already has a WireGuard mesh (Node0 hub, RHEL9 lab, owner's
    desktop). Putting the bench laptop on it as a fourth peer removes the
    jump host from the critical path entirely:
    ssh anatol@10.20.30.4
    mstsc /v:10.20.30.4
    That is strictly better than the autossh reverse tunnel it replaces. Both
    exist to survive the laptop's DHCP lease changing, but WireGuard also
    handles NAT traversal and roaming, is already deployed and understood
    here, and leaves one less bespoke moving part and one less machine whose
    downtime takes out access. The autossh phase is removed.
    setup-wireguard.sh generates the keypair on the lapto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
2026-08-12 Add ConnectBench.ps1, a sibling of ConnectLab.ps1 for the bench laptop
    Same structure and conventions as the RHEL9 connection script: WireGuard
    activation prompt, reachability checks with named diagnostics, then launch.
    Two routes, chosen automatically. If the laptop answers on the mesh at
    10.20.30.4 it connects DIRECT; otherwise it stands up an SSH forward
    through RHEL9 to the laptop's LAN address and connects to localhost:13389.
    Running setup-wireguard.sh on the laptop upgrades this script to DIRECT
    with no edits to it.
    Local port 13389 rather than 3389, because RHEL9's own xrdp already holds
    3389 and a forward there fails with "Address already in use".
    It writes an .rdp file that pins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
2026-08-13 Do not assume the hub interface is wg0
    Node0 carries more than one tunnel: the mesh is wg1 on port 51847, while
    wg0 is an unrelated 10.6.0.0/24 tunnel on 51820. The instruction this
    script printed would have registered the peer on the wrong interface and
    pushed a syncconf through a tunnel carrying two unrelated live sessions --
    and wg1's config has PostUp/PostDown iptables rules, so the down/up cycle
    someone might reach for instead would have churned firewall state too.
    Now tells the operator to identify the interface by listen port and public
    key, and restates that hub-side peers take their own /32 while only the
    spokes use the /24. Getting that backwards on the hub routes the whole
    mesh a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
2026-08-13 Rewrite the setup doc to match what was actually built
    The document described x11vnc, an autossh reverse tunnel, and Ubuntu 24.04.
    None of those survived contact with the hardware: the laptop is 26.04 on
    Wayland where x11vnc cannot attach to a display, and the lab's existing
    WireGuard mesh replaced the tunnel.
    Rewritten around what is running, with a new section 7 recording every
    failure and its cause -- the Wayland session type, the missing RDP TLS
    certificate, the login keyring never unlocking under autologin, the daemon
    caching credentials until restarted, Windows sending MicrosoftAccount\
    usernames, and the AllowedIPs asymmetry that made an extra Windows-side
    peer silently blackhole all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
2026-08-13 Rename the bench laptop to gogoj-laptop
    It is the owner's personal laptop doing a job, not a dedicated appliance,
    and the old name read as though the machine belonged to the project.
    "benchtop" was avoided because the docs already use that for the RHEL9
    desktop.
    BENCH_HOSTNAME drives hostnamectl, the mDNS name and the RDP certificate
    CN, so those follow automatically.
    The systemd, sshd and udev drop-ins are renamed 99-rmr-bench.* to 99-rmr.*
    to decouple them from the hostname entirely, and each write is now preceded
    by removing the old filename. Without that, a re-run would leave two udev
    rule files installing the same symlinks.
    Nothing about the WireGuard mesh changes: peers are identifi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
2026-09-01 Add Process Sequencer, Pi touch-panel bridge, and status tower; drop bench-laptop tooling
    - RMR_Controller.html / RMR_Touch.html: block-based Process Sequencer
    (Homing, Syringe, Spin Coater, UV, Stamp) with per-block Run, Enable
    checkboxes, Run All, and Repeat. In the touch UI it is the new Recipe tab.
    - Both UIs gain a swappable transport: Web Serial (file://) or a WebSocket
    bridge (served over http), auto-selected, so the Pi panel runs in any browser.
    - pi-panel/: Raspberry Pi serial<->WebSocket bridge (rmr_bridge.py) with an
    optional static file server, GPIO buttons, a status tower + buzzer, and an
    E-stop sense input; plus systemd unit, udev rules, config example, and README.
    -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
    [rmr_bridge.py]
2026-09-01 Convert syringe from E0 extruder to homeable K linear axis
    The syringe plunger gained a fully-open limit switch (pin 63), so it is
    converted from the sole extruder (E0) into a 6th linear axis (Marlin K,
    G-code letter 'C', EXTRUDERS 0). +C dispenses; C0 is fully open.
    Firmware:
    - K_DRIVER_TYPE, AXIS6_NAME 'C' (AXIS6_ROTATES off = linear), EXTRUDERS 0
    - K endstop on pin 63 (A9): USE_KMIN_PLUG, K_MIN_PIN 63, inverting true
    - INVERT_K_DIR true so -C homes toward the open switch; K_HOME_DIR -1
    - K_MAX_POS 135 (measured stroke); homing feed/bump arrays extended to 6
    - Removed the vestigial HEATER_0_PIN dummy (no hotend under EXTRUDERS 0)
    - G28.cpp unchanged; its patch already homes K last
    - Compi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
    [Configuration.h, Configuration_adv.h]
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2026-09-03 pi-panel: NC E-stop input and tower-red latch on motor-power loss
    rmr_bridge.py: support a normally-closed E-stop sense contact ("nc": true in
    rmr_io.json) so open == pressed and a cut/broken wire also alarms; seed the
    initial state at startup. Watch the Mega serial for "MOTOR POWER LOST" /
    "restored" (from the new firmware motor-power sense) and latch the status tower
    red until restore, independent of the E-stop aux contact.
    rmr_io.example.json: document the "nc" option and set nc:true on the estop entry.
    [rmr_bridge.py]
2026-09-03 docs: add CLAUDE.md gotchas for UV lid interlock and motor-power sense
    Gotcha 15 documents UV_LID_INTERLOCK (pin 39, M42 gate + idle auto-off,
    fail-safe, hardware interlock is primary). Gotcha 16 documents
    MOTOR_POWER_SENSE (pin 43, quick_stop + unhome + re-home gate, boot-safe
    arming, aux wiring, and the Pi bridge tower-red latch).
2026-09-03 Process Sequencer: reliability, syringe + stamp rework, real-time E-STOP, spincoater indexing (#98)
    * Sequencer: time out and surface a stuck command instead of hanging
    The sequencer waited for each command's 'ok' with no timeout, so if a step
    never completed - an axis not reaching its endstop during G28, or the USB
    link dropping mid-run - the run hung silently with no feedback ("stuck on
    homing, can't tell if it's hung up on one").
    seqAwaitOk now:
    - shows a live "Running <cmd>... Ns (waiting for ok)" status so a long or
    stalled step is visibly counting instead of frozen;
    - times out (default 90s; homing measured ~15s) and fails the block with a
    clear message naming the command, the li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
    [Configuration_adv.h]
2026-09-03 Add toast notifications for connect / device-lost / E-STOP (#103)
    A small showToast(message, type) utility (top-right, auto-dismissing, colour-coded
    info/success/warn/error) plus a toast container and CSS using the app theme vars.
    Wired into the events that benefit from a visible popup since the log can scroll
    away: connect success/failure, serial device lost, and E-STOP.
    Salvaged the toast idea from an old bench-edit stash; the rest of that stash (a
    board-resetting Web Serial auto-reconnect and calls to helpers that were never
    defined) is dropped.
    Claude-Session: https://claude.ai/code/session_01NQDEg8nvKFixDPDfvEQRS2
2026-09-03 Resolve committed conflict markers in SpincoaterStage/platformio.ini (#101)
    The file has carried unresolved git-stash conflict markers in main since 542ff45
    (2026-04-04): the "Updated upstream" side is the real [env:nanorp2040connect]
    config, the "Stashed changes" side was just the empty PlatformIO template.
    Restored the real config (identical to the last good spincoater commit 3d4f3fd);
    the file parses again. Standalone SpincoaterStage benchtop test firmware only --
    no effect on the RMR controller HTML or Marlin.
    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
2026-09-03 Stamp: fix feeder double-raise when alternating; add filter-feeder jog (#105)
    A single shared carriage (axis A) lifts both the left and right filter
    stacks together. Removing one filter from each side lowers both columns
    by one filter, so the carriage should rise by one stack height per L+R
    pair. The old code advanced the feeder on every pick, which raised the
    carriage twice per pair in alternating mode - each stack ended up raised
    by a full extra filter on its second visit. Left-only and right-only
    advance once per real pick, which was already correct.
    Fix: in alternating mode advance the feeder only once every two picks
    (once per pair). Left-only / right-only behavior is unchanged.
    Also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
2026-09-15 tests: stub canvas 2D, getPropertyValue, URLSearchParams, typed arrays in the DOM harness (#115)
    The UV / argon progress bar draws to a <canvas> during seqInit, so every
    test that loads a UI through the stub DOM crashed at startup on
    `canvas.getContext(...)` — masking the real assertions in ok-attribution,
    spin-markers, homing-indicator and run-log since the progress bar landed.
    Fill the gaps the shipped code touches on load:
    - getContext() returns a no-op 2D context (Proxy over the whole API).
    - getComputedStyle().getPropertyValue() returns '' so palette() falls
    back to its coded default colours.
    - expose URLSearchParams (transport init reads location.search).
    - share the outer realm's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
2026-09-15 Stamp: safe 3-step post-press retreat (abs Z75 -> Y to limit switch -> full up) (#114)
    After a press, retreat in three guarded absolute moves so nothing
    collides on the way out to the discard:
    1) raise to an ABSOLUTE Z=75 that clears the spincoater but stays below
    the stowed lid (was a relative Z-lift that only reached ~75 by
    coincidence of the press depth, and drifted when the depth changed),
    2) Y all the way back to the min limit switch (Y0) to clear the syringe
    — a hard mechanical reference, not a relative back-off,
    3) only then go fully up to the safe Z, which clears the stowed
    spincoater lid.
    Applied to both UIs. The Touch stamp block previously went straigh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
2026-09-15 Docs: refresh 2026-09-14 handoff with the later merges and the tooling/test quirks (#116)
    Record the second 2026-09-14 session so a new agent inherits it:
    - §2: new subsection for #111–#115 (travel limits C=125/B=300, stamp
    coords X122.3 Y27.3 Z155, absolute post-press retreat Z75→Y0→safeZ,
    syringe prime button, harness fix), with the resulting current values
    and the #113/#114 adjacent-line merge conflict.
    - §4: the stub harness now runs (portable Node in ~/.local); the suite is
    12 passed / 3 failed, and the 3 are the live issue-#48 bug, not noise
    and not a new regression — #115 unmasked them by fixing the canvas crash.
    - §5 item 6: there is now a runnable regression tes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
2026-09-15 Stamp: Touch feeder advances A- once per L/R pair; lift-Z guard in both UIs (#118)
    * Stamp: fix Touch feeder direction (A-) and once-per-pair advance; lift-Z guard in both UIs
    RMR_Touch.html advanced the filter feeder with a relative G1 A+<stack>. The
    feeder (Marlin I axis, letter A) homes to MAX (I_HOME_DIR 1, I_MAX_POS 343),
    so after homing the soft endstop clamps that move and the feeder never
    advances; mid-stack it lowers the stack instead of raising it. Port the
    Controller's feeder logic (#98/#105): advance with G1 A-<stack>, once per
    pick, or once per L+R pair when alternating (one shared carriage lifts both
    stacks), with the same comment; Touch field ids unchanged.
    Reconcile the gri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

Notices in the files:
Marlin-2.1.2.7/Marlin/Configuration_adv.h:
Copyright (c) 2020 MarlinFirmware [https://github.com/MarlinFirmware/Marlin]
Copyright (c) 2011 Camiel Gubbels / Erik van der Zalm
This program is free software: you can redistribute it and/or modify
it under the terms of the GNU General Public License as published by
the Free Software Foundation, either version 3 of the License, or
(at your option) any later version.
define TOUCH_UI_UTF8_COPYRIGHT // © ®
